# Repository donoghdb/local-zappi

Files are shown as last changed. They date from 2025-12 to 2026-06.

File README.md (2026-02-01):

# Myenergi Zappi V2.x Local Controller (ESP32-S3)

<p align="center">
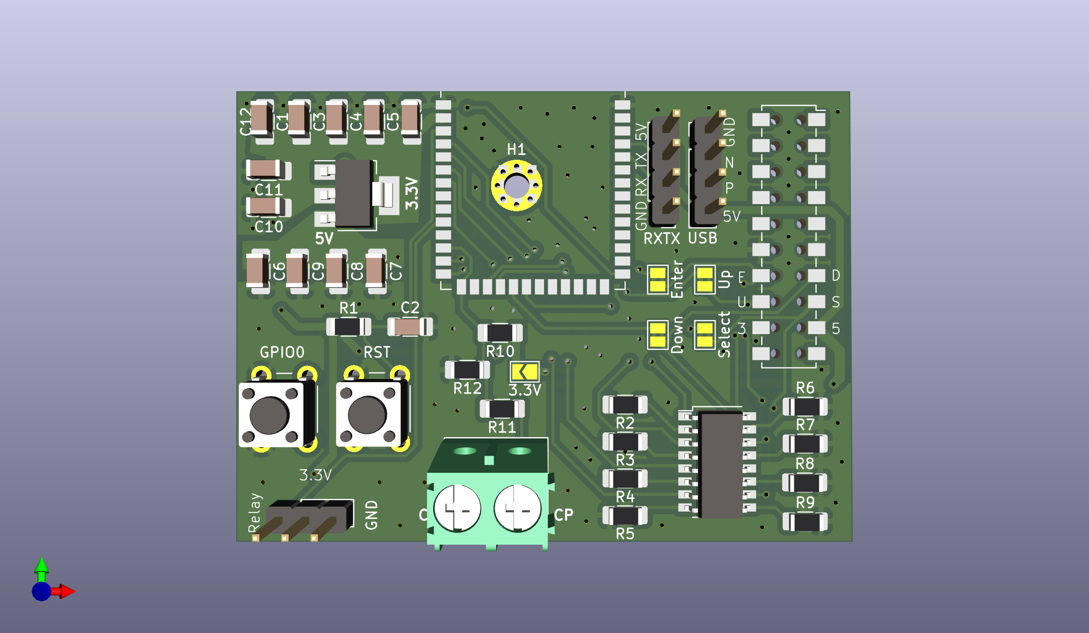
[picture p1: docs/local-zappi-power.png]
  
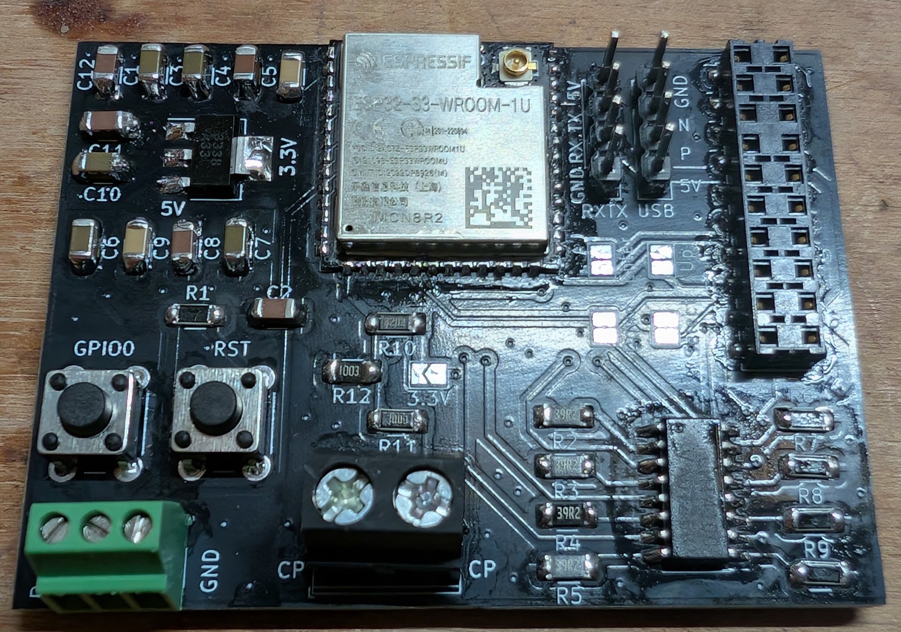
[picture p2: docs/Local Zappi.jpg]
  
</p>

A dedicated hardware implant for Myenergi Zappi V2.x EV Chargers. This project interfaces directly with the Zappi's internal control bus to provide **Local MQTT**, **Home Assistant**, and **Web Control** without relying on the Myenergi Cloud or Hub. It is intended to action on the 4 external buttons while monitoring the EVSE CP line conversation between the Zappi and the car. It does not affect the software of the Zappi nor does it affect anything else. So it can be removed without affecting anything else.

## ⚠️ DANGER: HIGH VOLTAGE
**This device is installed INSIDE a 240V/400V EV Charger.**
* **Isolate power completely** at the consumer unit/breaker before opening the Zappi.
* High voltage components are centimeters away from the installation area.
* **Use at your own risk.** Improper installation can damage your charger, vehicle, or cause injury.

## 🔌 How It Works
This PCB intercepts the connection between the Zappi **Main Control Board** and the **Front Panel (Display & Buttons)**.

1.  **Power (5V):** Draws power directly from the Zappi's internal 5V rail (no external USB power needed).
2.  **Button Interface:**
    * **Read Mode:** Monitors the 4 physical buttons (Enter, Up, Down, Select) so you can still use the Zappi manually.
    * **Write Mode:** Simulates button presses using Optocouplers/Relays, allowing you to control the menu remotely via WiFi.
3.  **J1772 Pilot Reading:**
    * Taps into the CP (Control Pilot) line to detect accurate Status (A-F) and PWM Duty Cycle (Amps).

## 🛠️ Hardware Interface
The design utilizes an **ESP32-S3-WROOM-1** and integrates via the internal 20-pin Ribbon Header.

| Signal | Function | Connection |
| :--- | :--- | :--- |
| **5V / GND** | Power Supply | Taken from Zappi internal header. |
| **Buttons** | Enter, Up, Down, Select | **Bi-directional:** Reads physical presses & triggers simulated presses via Optocouplers (TCMT4100). |
| **CP Signal** | J1772 State Detection | Read ±12V Pilot Signal. |
| **Boost Relay** | e-Sense Port trigger | Enable via relay. |

### Pinout Configuration (ESP32-S3)
*Based on PCB Revision 1.1*
* **Button Inputs:** GPIO 4, 5, 6, 7
* **Button Triggers:** GPIO 12, 13, 14, 15
* **CP Signal (ADC):** GPIO 8
* **CP Interrupt:** GPIO 3
* **Relay:** GPIO 17

## 💻 Software / Firmware
This project supports two firmware paths depending on your needs:

### Option A: ESPHome (Not complete yet)
Best for **Home Assistant** users. Provides native integration with zero coding.
* Exposes Buttons as simple HA Switches.
* Exposes Charging Amps and State as Sensors.
* **Config:** Copy `esphome/zappi.yaml` and `esphome/zappi_logic.h` to your ESPHome directory.
* Limitations: Does not monitor or track the menu position. The monitoring of the Zappi buttons is not tested yet.

### Option B: Custom C++ Firmware (Best Option)
Best for standalone use or custom MQTT setups.
## 🌟 Features
* **Full Local Control:** No cloud dependency. Works with Home Assistant via MQTT.
* **Offline Scheduler:** Set Start/End times directly on the device via text input (e.g., "07:30"). It handles the mode switching (Stopped ↔ Fast) automatically.
* **Robust Time Sync:**
    * **Primary:** NTP via Google/NIST (Direct IP to bypass DNS issues).
    * **Backup:** "Push" time via MQTT from Home Assistant (works during internet outages).
    * **Safety:** Scheduler only activates once the system year is verified > 2020.
* **Live Monitoring:** View Charging State, Pilot Amps, Duty Cycle, and RSSI.
* **Menu Navigation:** Remotely navigate the Zappi menu using the Web UI or HA.
* **Reliability:** Includes "Last Will & Testament" (LWT) so Home Assistant immediately knows if the device loses power.
* **Others:** Web Interface, WebSocket Live Data, WebSerial, OTA Updates.
* **Tech Stack:** PlatformIO, AsyncWebServer.

## 🔐 Configuration (Custom Firmware)

To keep your WiFi and MQTT passwords safe, this project uses a separate credentials file that is **ignored by Git**.

### 1. Create `src/credentials.cpp`
Create a new file in the `src/` folder named `credentials.cpp` and copy the code below. **Update the values with your actual network details.**

```cpp
#include "credentials.h"
#include <Arduino.h> // for IPAddress

// WiFi Credentials
const char* ssid = "YOUR_WIFI_SSID";
const char* password = "YOUR_WIFI_PASSWORD";

// MQTT Broker Details
const char* mqttServer = "192.168.1.50";
const int mqttPort = 1883;
const char* mqttUser = "homeassistant";
const char* mqttPassword = "mqtt_password";
const char* mqttClientId = "Zappi_Controller";

// Static IP Configuration (Optional)
// Set to 0.0.0.0 if you want to use DHCP
IPAddress staticIP(192, 168, 1, 200);
IPAddress gateway(192, 168, 1, 1);
IPAddress subnet(255, 255, 255, 0);
```

### 2. MQTT Topics
The device uses the base topic `zappi/` (configurable).
* **Controls:** `zappi/button/...`
* **Sensors:** `zappi/sensor/...`
* **Status:** `zappi/status` (online/offline)
* **Scheduler:**
    * Enable: `zappi/switch/zap_sch_en/command` (ON/OFF)
    * Start Time: `zappi/text/zap_sch_start/set` (HH:MM)
    * End Time: `zappi/text/zap_sch_end/set` (HH:MM)
    * Force Time Sync: `zappi/time/set_epoch` (Epoch Timestamp)

## ⚡ Installation (Custom Firmware / PlatformIO)

This method allows you to use the full Web Interface and custom C++ logic.

### 1. Initial Setup (USB)
1.  Clone this repository and open the `firmware_custom` folder in **VS Code** with the **PlatformIO** extension installed.
2.  Connect your ESP32-S3 to your computer via USB.
3.  Open `platformio.ini` and ensure the OTA lines are **commented out** (so it uses USB upload by default):
    ```ini
    ; upload_protocol = espota
    ; upload_port = 192.168.1.X
    ```
4.  Click the **Upload** arrow (→) in the bottom toolbar to flash the firmware.

### 2. Upload the Web Interface (Filesystem)
The HTML files live in a separate partition called LittleFS. You must upload this once, or the web page will be blank.

1.  Click the **PlatformIO Alien Icon** on the left sidebar.
2.  Navigate to: **Project Tasks** → **Platform**.
3.  Click **Upload Filesystem Image**.
4.  Wait for the success message. Your ESP32 will reboot.
5.  The HTML can be updated directly from the webserver later via an Upload page.

### 3. Connect & Use
1.  Search for the WiFi Network: `Zappi-AP` (Password: `password123` or as configured).
2.  Navigate to `http://192.168.4.1` (or the IP assigned by your router).
3.  You should see the Zappi Control Dashboard.

### 4. Future Updates via OTA (Wireless)
Once the device is installed inside the Zappi case, you can update it wirelessly:
1.  Find the IP address of your Zappi Controller (e.g., `192.168.1.50`).
2.  Edit `platformio.ini` and uncomment the OTA lines:
    ```ini
    upload_protocol = espota
    upload_port = 192.168.1.50  ; Replace with your actual IP
    ```
3.  Click **Upload** in PlatformIO. It will now flash over WiFi.

## 🔧 Hardware Installation Guide
1.  **Power Off:** Turn off the Zappi at the breaker.
2.  **Open Case:** Remove the front fascia and unscrew the main cover.
3.  **Locate Header:** Find the 20-pin pin header connecting the main PCB to the screen module.
4.  **Seperate boards:** Use a needle nose pliers to compress each corner connecting pin and carfully seperate the boards.
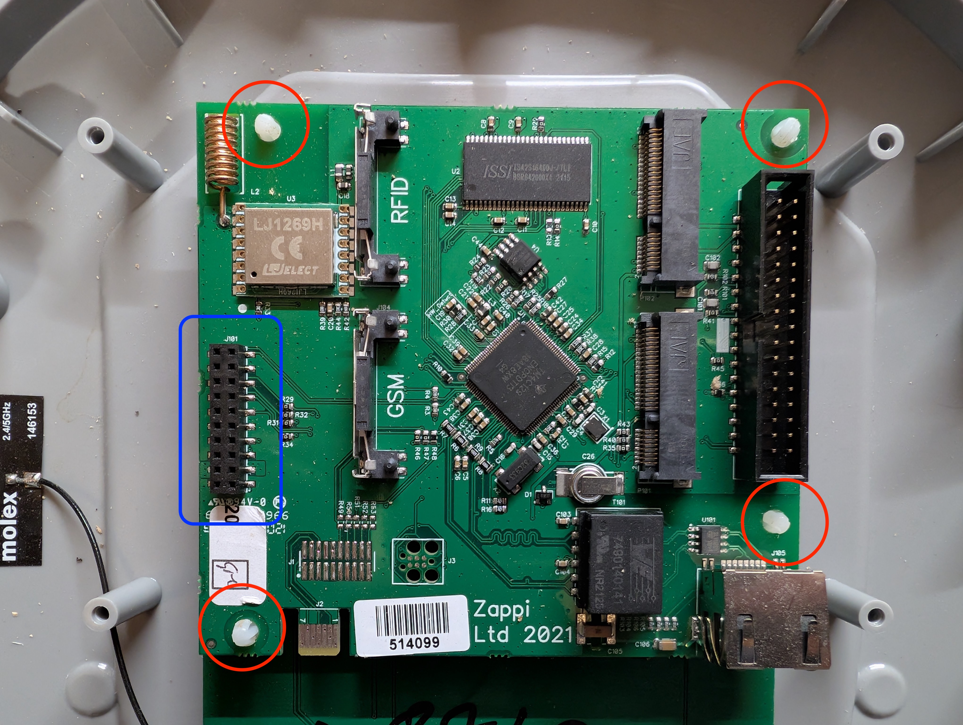
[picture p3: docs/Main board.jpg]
20 pin in Blue, connecting pins in Red

5.  **Extend Header:** Extend the header using this component Samtec EW-10-12-G-D-250 or this one EW-10-13-G-D-200.
6.  **Connect:** With the extended header connect the boards back together and then attach the ESP32 board.
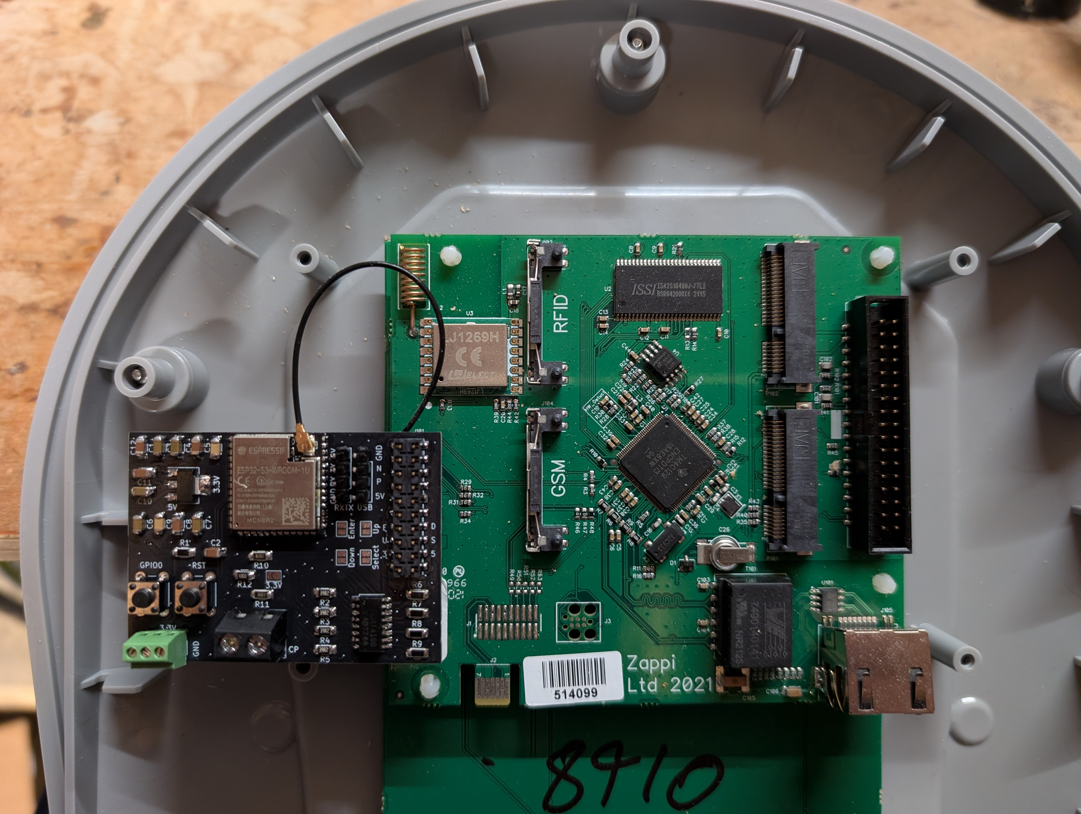
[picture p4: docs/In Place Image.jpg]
Local ESP32 in place, with Molex connector for Wifi

7.  **Connect CP:** Attach the single sensing wire to the CP terminal block.
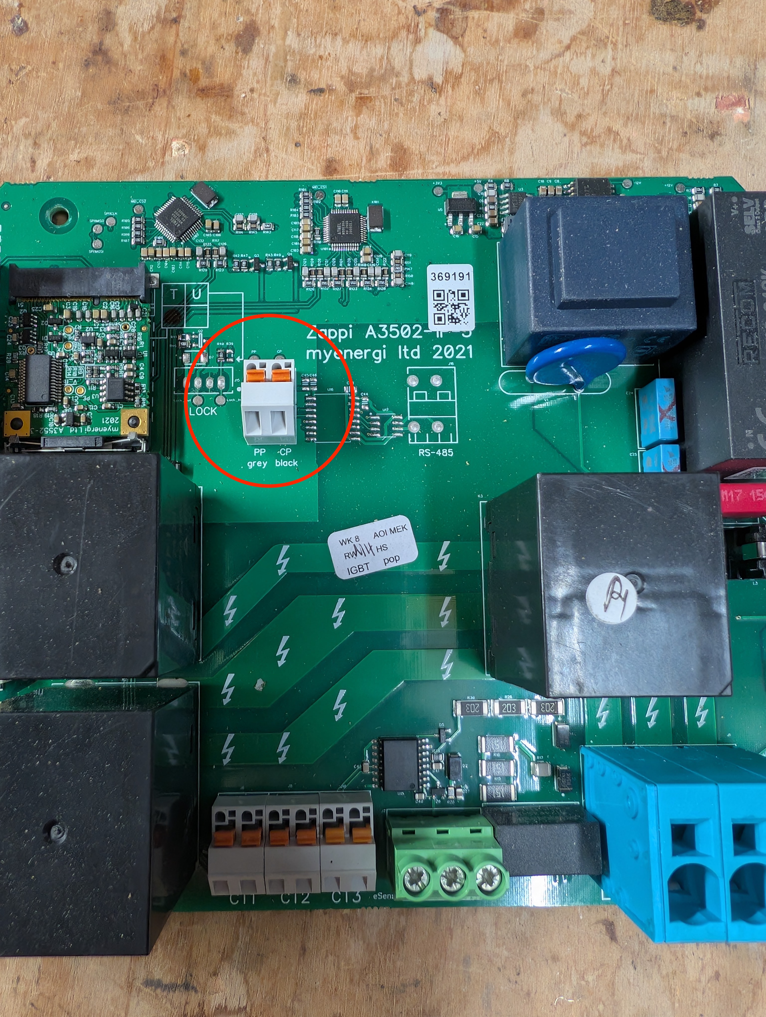
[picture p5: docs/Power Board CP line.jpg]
Attach or Extend the CP line to the ESP32

8.  **e-Sence:** Attached the 24V output of the zappi power board to the Common Relay connector and the Normally Closed to the e-Sence input on the zappi power board.
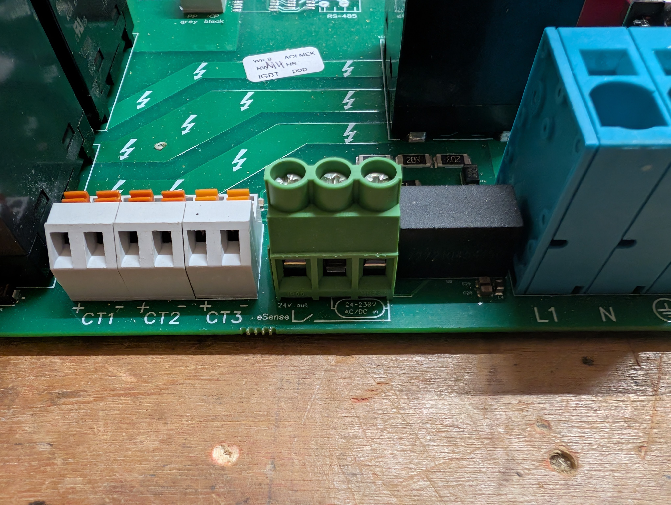
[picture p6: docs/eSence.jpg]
eSence connection 24V to Input via Relay

9.  **Wifi:** Attach the Zappi existing antenna to the new board or install a new on. Or else create it with this varient ESP32-S3-WROOM-1-N8R2
10.  **Close & Power Up:** Reassemble and restore power.

## 🔌 Schematic
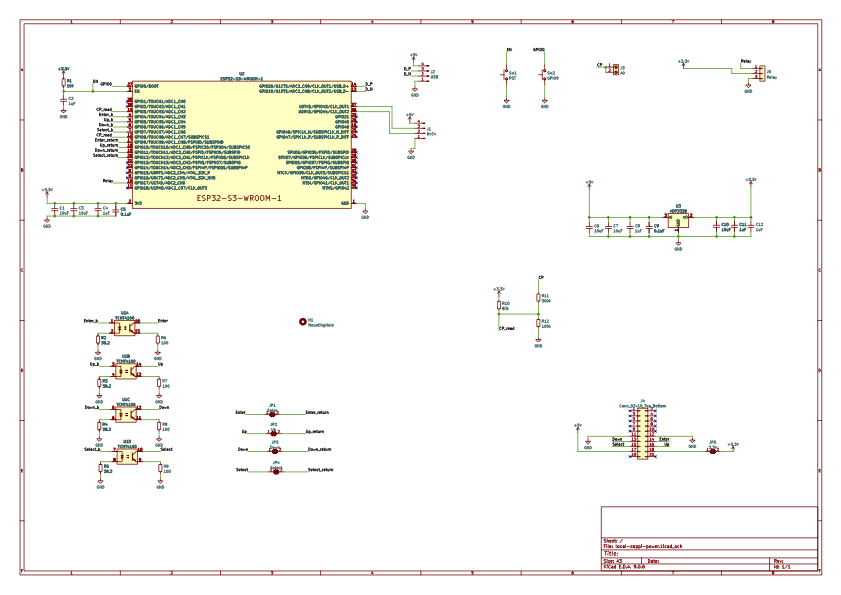
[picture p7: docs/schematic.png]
Schematic Preview

*[Download Full PDF Schematic](docs/local-zappi-power.pdf)*

## 🧩 Bill of Materials (BOM)

This project requires a custom PCB or a perfboard setup designed to fit inside the Zappi case.
There is more Decoupling capacitators than required. Sometimes the power rails dip when the Zappi triggers its own relays. 

### Active Components
| Ref | Component | Description | Notes |
| :--- | :--- | :--- | :--- |
| **U2** | **ESP32-S3-WROOM-1** | MCU Module | Schematic specifies WROOM-1 (PCB Antenna). If using the `1U` version, connect an external IPEX antenna. |
| **U3** | **ADP3338** | 3.3V LDO Regulator | Steps down the Zappi 5V rail to 3.3V for the ESP32. |
| **U1** | **TCMT4100** | Quad Optocoupler | **U1:** Simulates button presses. |

### Passive Components
| Ref | Value | Quantity | Description |
| :--- | :--- | :--- | :--- |
| **R1** | **10kΩ** | 1 | Pull up to 3.3V for ESP32 Enable Pin. |
| **R2-R5** | **39.2Ω** | 4 | Current limiting for Optocoupler LEDs. |
| **R6-R9** | **100Ω** | 4 | Pull/Protection for button return lines. |
| **R10** | **82kΩ** | 1 | Pull up to 3.3V Pilot Signal divider (CP to ADC), 1% Tolerance required. |
| **R11** | **300kΩ** | 1 | High-side Pilot Signal divider (CP to ADC), 1% Tolerance required. |
| **R12** | **100kΩ** | 1 | Low-side Pilot Signal divider (ADC to GND), 1% Tolerance required. |
| **C6, C7, C10, C1, C3** | **10µF** | 4 | Bulk capacitance for LDO & 3.3V Rails. |
| **C2, C4, C8, C11, C12** | **1µF** | 4 | Stability capacitance for LDO. |
| **C5, C9** | **0.1µF** | 2 | Decoupling for ESP32 and Power rails. |

### Connectors
| Component | Quantity | Purpose |
| :--- | :--- | :--- |
| **20-Pin Header** | 1 | 2x10 Samtec (HLE-110-02-L-DV-BE-K-TR) to interface with Zappi mainboard. |
| **2-Pin Terminal** | 1 | Screw terminal for CP (Pilot) wire connection. |
| **3-Pin Header/Terminal** | 1 | Optional Relay/GPIO breakout (JP5). |
| **Buttons** | 2 | Reset and GPIO 0 button. |
| **Mini Relay** | 1 | Optional: Adafruit STEMMA Non-Latching Mini Relay. |

## 🕒 Scheduler & Time Sync
The device includes a **System Time Sensor** (`sensor.system_time`) to show you exactly what time the internal clock thinks it is.

### How it works:
1.  **On Boot:** The device attempts to sync time via NTP using Google & NIST IPs (bypassing local DNS issues).
2.  **Safety Check:** The scheduler **will not run** until the year is > 2020. This prevents the charger from triggering at the wrong time (e.g., 1970).
3.  **Offline Backup:** If your internet is down, Home Assistant can "push" the time to the Zappi via MQTT automation using the topic `zappi/time/set_epoch`.

## 🧪 Testing the CP (Pilot) Signal (Optional Extra if you want to verify the device before installing it)

The Control Pilot (CP) line communicates the state of the EVSE to the car using specific voltage levels (+12V, +9V, +6V) and a 1kHz PWM signal.

Since we are using a **Passive Resistor Divider (300kΩ / 100kΩ)**, it is critical to verify the voltage levels before relying on the automation.

### 1. Bench Testing 
Before installing the unit into the Zappi, you can verify the voltage divider logic using a DC Power Supply or a simple 9V battery.

1.  **Disconnect the ESP32** (if possible) or ensure it is unpowered.
2.  **Apply Voltage** to the CP Terminal on your custom board:
    * **Input 12V:** Measure the voltage at the ESP32 GPIO 8 pin. It should be **~3.0V**.
    * **Input 9V:** Measure the voltage at GPIO 8. It should be **~2.25V**.
3.  **Verify:** If you see >3.3V at the GPIO pin, **STOP**. Your resistor values are incorrect, and you risk frying the ESP32.

### 2. Live Signal Verification
Once installed in the Zappi, use the **WebSerial** (Custom Firmware) or **Home Assistant Logs** (ESPHome) to view the raw ADC readings.

#### Expected ADC Values (12-bit Resolution)
The code looks for the **Peak Voltage** of the signal. Here is what you should see in the logs:

| State | J1772 Voltage | Divider Output | Target ADC Raw |
| :--- | :--- | :--- | :--- |
| **A (Unplugged)** | +12V | ~3.0V | **3600 - 4095** |
| **B (Connected)** | +9V | ~2.25V | **3100 - 3600** |
| **C (Charging)** | +6V (PWM) | ~1.5V | **2500 - 3100** |
| **D (Ventilation)** | +3V (PWM) | ~0.75V | **1900 - 2500** |
| **F (Error/Fault)** | -12V | -3.0V* | **< 1500** |

*> **Note:** The passive divider will pass negative voltages to the GPIO. Ensure your protection diode is in place, or that the ESP32 inputs are clamped effectively to prevent damage during State F.*

### 3. Verifying Amperage (PWM)
When the car enters **State C (Charging)**, the Zappi generates a 1kHz Square Wave.
1.  Check the **"Zappi Duty Cycle"** sensor.
2.  Compare it to the Zappi Screen.
    * **Formula:** `Amps = Duty Cycle x 0.6`
    * *Example:* A 50% Duty Cycle should display as **30A**.

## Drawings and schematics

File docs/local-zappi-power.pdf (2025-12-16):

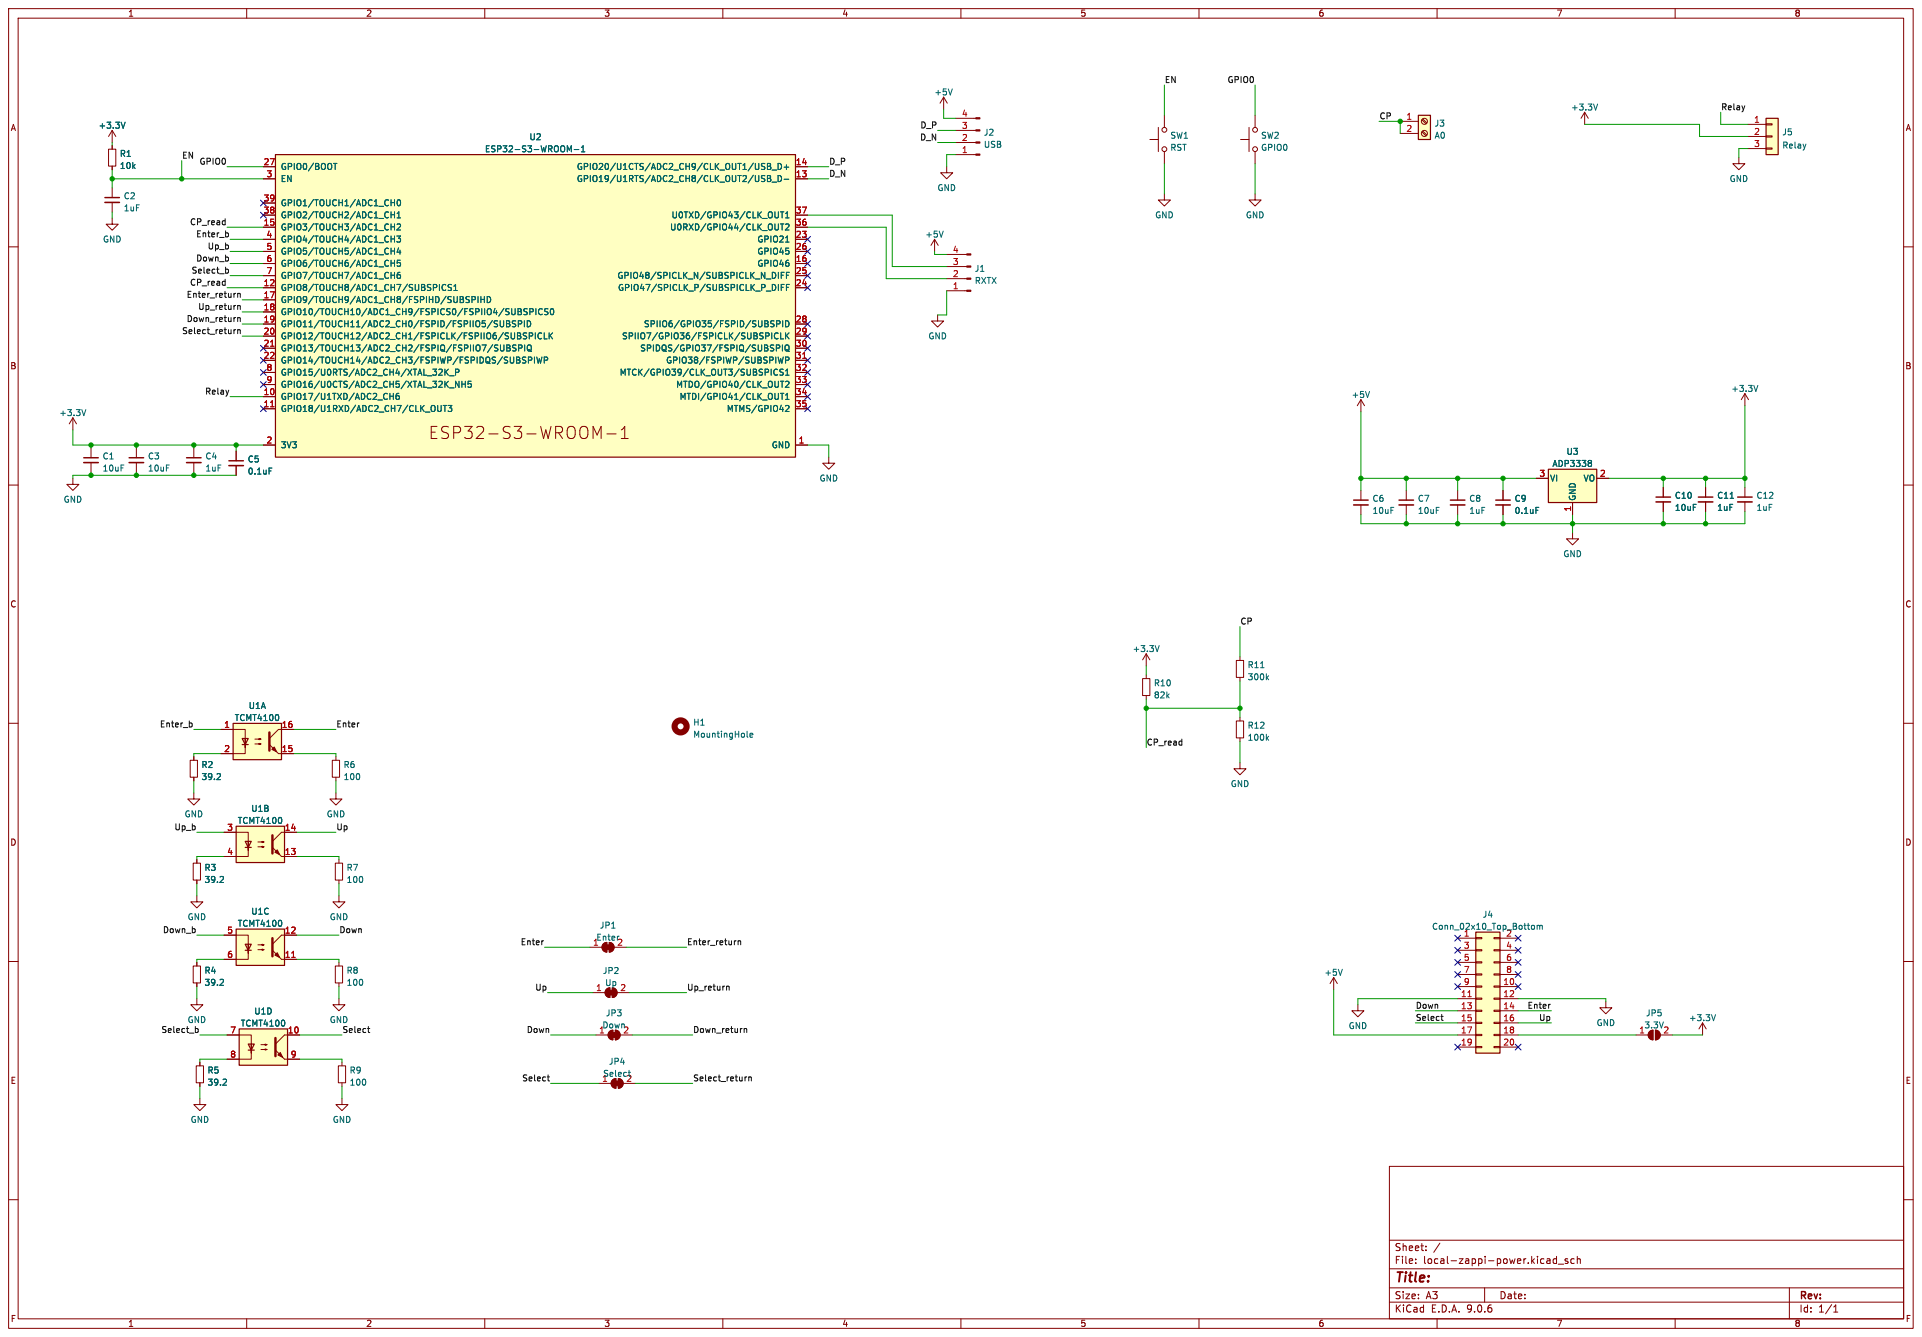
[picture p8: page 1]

1 VO 2 U2 ESP32-S3-WROOM-1 GPIO0/BOOT 27 EN 3 GPIO1/TOUCH1/ADC1_CH0 39 GPIO2/TOUCH2/ADC1_CH1 38 GPIO3/TOUCH3/ADC1_CH2 15 GPIO4/TOUCH4/ADC1_CH3 4 GPIO5/TOUCH5/ADC1_CH4 5 GPIO6/TOUCH6/ADC1_CH5 6 GPIO7/TOUCH7/ADC1_CH6 7 GPIO8/TOUCH8/ADC1_CH7/SUBSPICS1 12 GPIO9/TOUCH9/ADC1_CH8/FSPIHD/SUBSPIHD 17 GPIO10/TOUCH10/ADC1_CH9/FSPICS0/FSPIIO4/SUBSPICS0 18 GPIO11/TOUCH11/ADC2_CH0/FSPID/FSPIIO5/SUBSPID 19 GPIO12/TOUCH12/ADC2_CH1/FSPICLK/FSPIIO6/SUBSPICLK 20 GPIO13/TOUCH13/ADC2_CH2/FSPIQ/FSPIIO7/SUBSPIQ 21 GPIO14/TOUCH14/ADC2_CH3/FSPIWP/FSPIDQS/SUBSPIWP 22 GPIO15/U0RTS/ADC2_CH4/XTAL_32K_P 8 GPIO16/U0CTS/ADC2_CH5/XTAL_32K_NH5 9 GPIO17/U1TXD/ADC2_CH6 10 GPIO18/U1RXD/ADC2_CH7/CLK_OUT3 11

Id: 1/1 Title: File: local-zappi-power.kicad_sch Sheet: /

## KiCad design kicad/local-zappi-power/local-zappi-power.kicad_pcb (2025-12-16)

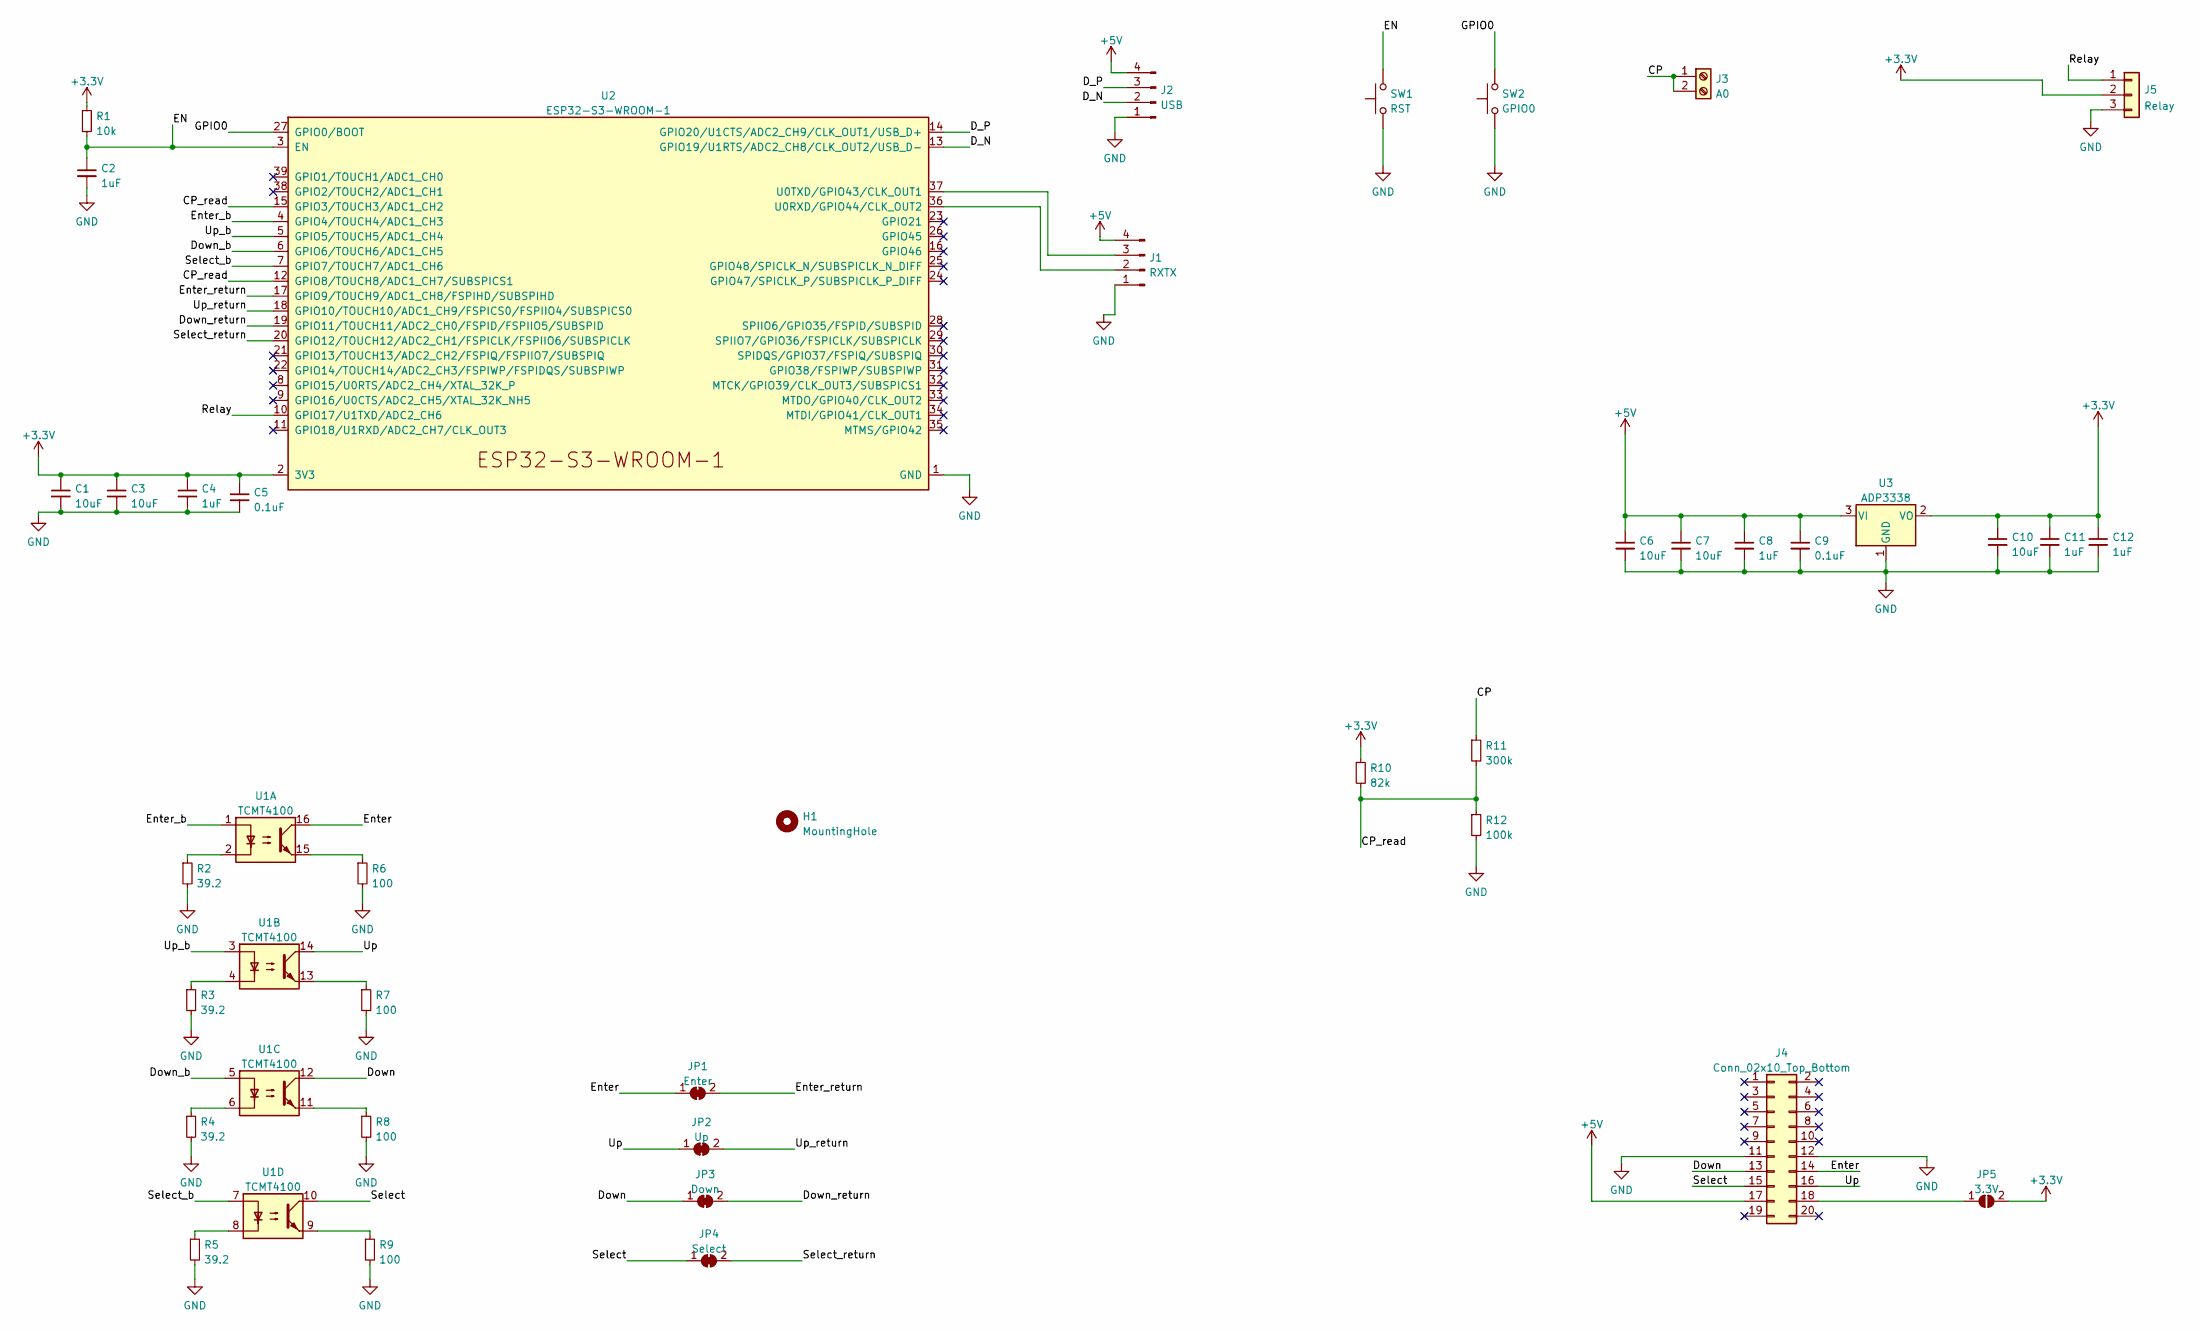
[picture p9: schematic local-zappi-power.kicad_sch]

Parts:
C1, C3, C6, C7, C10: 10uF; C_1206_3216Metric_Pad1.33x1.80mm_HandSolder; Mouser GMK316BJ106KL-T
C2, C4, C8, C11, C12: 1uF; C_1206_3216Metric_Pad1.33x1.80mm_HandSolder; Mouser 12065C105K4Z4A
C5, C9: 0.1uF; C_1206_3216Metric_Pad1.33x1.80mm_HandSolder; Mouser 581-KAM31NR72A104KU
H1: MountingHole; MountingHole_2.5mm_Pad_Via
J1: RXTX; PinHeader_1x04_P2.54mm_Vertical
J2: USB; PinHeader_1x04_P2.54mm_Vertical
J3: A0; TerminalBlock_Phoenix_PT-1,5-2-5.0-H_1x02_P5.00mm_Horizontal; Mouser 651-5441537
J4: Conn_02x10_Top_Bottom; Samtec_HLE-110-02-xxx-DV-BE_2x10_P2.54mm_Horizontal
J5: Relay; PinHeader_1x03_P2.54mm_Vertical
JP1: Enter; SolderJumper-2_P1.3mm_Bridged2Bar_Pad1.0x1.5mm
JP2: Up; SolderJumper-2_P1.3mm_Bridged2Bar_Pad1.0x1.5mm
JP3: Down; SolderJumper-2_P1.3mm_Bridged2Bar_Pad1.0x1.5mm
JP4: Select; SolderJumper-2_P1.3mm_Bridged2Bar_Pad1.0x1.5mm
JP5: 3.3V; SolderJumper-2_P1.3mm_Open_TrianglePad1.0x1.5mm
R1: 10k; R_1206_3216Metric_Pad1.30x1.75mm_HandSolder; Mouser CRCW120610K0FKEA
R2, R3, R4, R5: 39.2; R_1206_3216Metric_Pad1.30x1.75mm_HandSolder; Mouser CRCW120639R2FKEAC
R6, R7, R8, R9: 100; R_1206_3216Metric_Pad1.30x1.75mm_HandSolder; Mouser CRCW1206100RJNEA
R10: 82k; R_1206_3216Metric_Pad1.30x1.75mm_HandSolder; Mouser ESR18EZPF8202
R11: 300k; R_1206_3216Metric_Pad1.30x1.75mm_HandSolder; Mouser KTR18EZPF3003
R12: 100k; R_1206_3216Metric_Pad1.30x1.75mm_HandSolder; Mouser CRGP1206F100K
SW1: RST; SW_PUSH_6mm_H4.3mm
SW2: GPIO0; SW_PUSH_6mm_H4.3mm
U1: TCMT4100; SOP-16_4.4x10.4mm_P1.27mm
U2: ESP32-S3-WROOM-1
U3: ADP3338; SOT-223-3_TabPin2; Mouser 584-ADP3338AKCZ3.3R

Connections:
+3.3V: C1.1, C3.1, C4.1, C5.1, C10.1, C11.1, C12.1, J5.2, JP5.2 (B), R1.1, R10.1, U2.2 (3V3), U3.2 (VO)
+5V: C6.1, C7.1, C8.1, C9.1, J1.4, J2.4, J4.17, U3.3 (VI)
/CP: J3.1, J3.2, R11.1
/CP_read: R10.2, R11.2, R12.1, U2.12 (GPIO8/TOUCH8/ADC1_CH7/SUBSPICS1), U2.15 (GPIO3/TOUCH3/ADC1_CH2)
/D_N: J2.2, U2.13 (GPIO19/U1RTS/ADC2_CH8/CLK_OUT2/USB_D-)
/D_P: J2.3, U2.14 (GPIO20/U1CTS/ADC2_CH9/CLK_OUT1/USB_D+)
/Down: J4.13, JP3.1 (A), U1.12
/Down_b: U1.5, U2.6 (GPIO6/TOUCH6/ADC1_CH5)
/Down_return: JP3.2 (B), U2.19 (GPIO11/TOUCH11/ADC2_CH0/FSPID/FSPIIO5/S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)
/EN: C2.1, R1.2, SW1.2, U2.3 (EN)
/Enter: J4.14, JP1.1 (A), U1.16
/Enter_b: U1.1, U2.4 (GPIO4/TOUCH4/ADC1_CH3)
/Enter_return: JP1.2 (B), U2.17 (GPIO9/TOUCH9/ADC1_CH8/FSPIHD/SUBSPIHD)
/GPIO0: SW2.2, U2.27 (GPIO0/BOOT)
/Relay: J5.1, U2.10 (GPIO17/U1TXD/ADC2_CH6)
/Select: J4.15, JP4.1 (A), U1.10
/Select_b: U1.7, U2.7 (GPIO7/TOUCH7/ADC1_CH6)
/Select_return: JP4.2 (B), U2.20 (GPIO12/TOUCH12/ADC2_CH1/FSPICLK/FSPIIO6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)
/Up: J4.16, JP2.1 (A), U1.14
/Up_b: U1.3, U2.5 (GPIO5/TOUCH5/ADC1_CH4)
/Up_return: JP2.2 (B), U2.18 (GPIO10/TOUCH10/ADC1_CH9/FSPICS0/FSPIIO4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)
GND: C1.2, C2.2, C3.2, C4.2, C5.2, C6.2, C7.2, C8.2, C9.2, C10.2, C11.2, C12.2, H1.1, J1.1, J2.1, J4.11, J4.12, J5.3, R2.2, R3.2, R4.2, R5.2, R6.2, R7.2, R8.2, R9.2, R12.2, SW1.1, SW2.1, U2.1 (GND), U2.40 (GND), U2.41 (GND), U3.1 (GND)
unnamed: J1.2, U2.36 (U0RXD/GPIO44/CLK_OUT2)
unnamed: J1.3, U2.37 (U0TXD/GPIO43/CLK_OUT1)
unnamed: J4.18, JP5.1 (A)
unnamed: R2.1, U1.2
unnamed: R3.1, U1.4
unnamed: R4.1, U1.6
unnamed: R5.1, U1.8
unnamed: R6.1, U1.15
unnamed: R7.1, U1.13
unnamed: R8.1, U1.11
unnamed: R9.1, U1.9

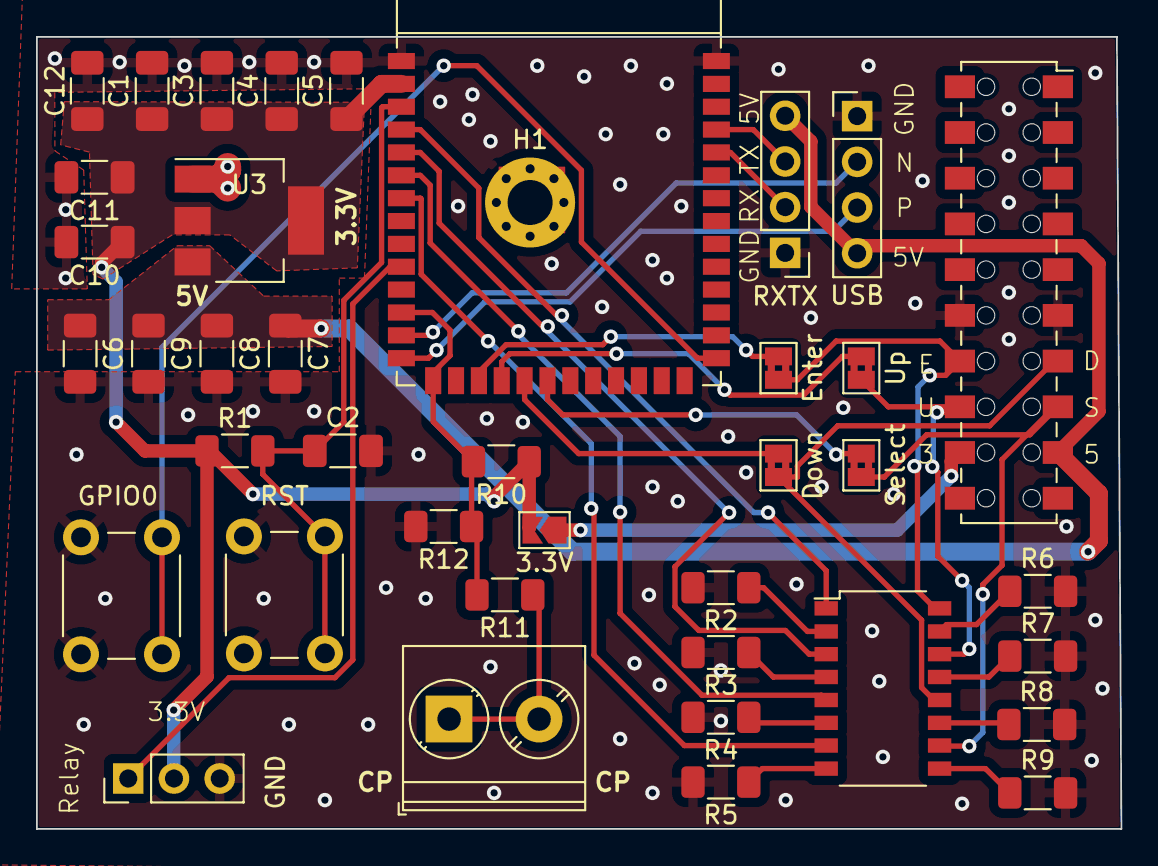
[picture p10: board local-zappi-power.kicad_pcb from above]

Board: 2 copper layers, 60.2 x 44.0 mm, 40 parts (0 on the bottom side), 33 nets.

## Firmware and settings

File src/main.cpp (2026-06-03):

#include <Arduino.h>
#include "globals.h"
#include "hardware.h"
#include "menu_system.h"
#include "wifi_mqtt.h"
#include "web_server.h"
#include <ArduinoOTA.h>
#include "credentials.h"
#include <ESPmDNS.h>
#include <esp_task_wdt.h>
#include <esp_ota_ops.h>
#include <esp_partition.h>
#include "soc/soc.h"
#include "soc/rtc_cntl_reg.h"



void setup() {
  WRITE_PERI_REG(RTC_CNTL_BROWN_OUT_REG, 0); // Disable Brownout Detector
  Serial.begin(115200);
  DEBUG_PRINTLN("Zappi Controller Starting...");

  // 1. Data & Globals
  prefs.begin("zappi", false);
  currentMode = prefs.getInt("currentMode", 1);
  counterDirty = false;
  // Load Schedule from Memory (NVS)
  schedEnabled   = prefs.getBool("schedEnabled", true);
  schedStartHour = prefs.getInt("schedStartH", 2); // 2 AM
  schedStartMin  = prefs.getInt("schedStartM", 0);
  schedEndHour   = prefs.getInt("schedEndH", 6); // 6 AM
  schedEndMin    = prefs.getInt("schedEndM", 0);
  

  // 2. Hardware (Pins & Interrupts)
  setupHardware();
  setupLogMenus();
  setupChargeSettingsMenus();

  // 3. START TASKS
  // ============================================================
  xTaskCreatePinnedToCore(counterNvsTask, "CounterNVS", 4096, NULL, 1, &counterNvsTaskHandle, 1);
  xTaskCreatePinnedToCore(buttonReleaseTask, "BtnRelTask", 4096, NULL, 1, &buttonReleaseTaskHandle, 1);
  xTaskCreatePinnedToCore(returnHandlerTask, "ReturnTask", 4096, NULL, 2, &returnHandlerTaskHandle, 1);
  xTaskCreatePinnedToCore(rssiPublishTask, "RSSITask", 4096, NULL, 1, &rssiPublishTaskHandle, 1);
  xTaskCreatePinnedToCore(adcMeasurementTask, "ADCTask", 10000, NULL, 1, &updateADC, 0); // Core 0 for ADC
  // ============================================================

  // 4. Create Timers
  mqttReconnectTimer = xTimerCreate("mqttTimer", pdMS_TO_TICKS(5000), pdFALSE, nullptr, [](TimerHandle_t) { connectToMqtt(); });
  wifiReconnectTimer = xTimerCreate("wifiTimer", pdMS_TO_TICKS(5000), pdFALSE, nullptr, [](TimerHandle_t) { connectToWifi(); });
  
  // Menu Timer (Prevent crash on menu open)
  menuTimeoutTimer = xTimerCreate("menuTimer", pdMS_TO_TICKS(3600000), pdFALSE, (void*)0, [](TimerHandle_t xTimer){
      extern void resetMenuToOff();
      resetMenuToOff(); 
  });

  // 5. Network Configuration
  WiFi.onEvent([](WiFiEvent_t event, WiFiEventInfo_t info){
      // Call your original callback
      wifiConnected(event, info);
      
      // AND restart mDNS now that we are 100% sure we have an IP
      if (MDNS.begin("evcharger")) {
         MDNS.addService("http", "tcp", 80);
         DEBUG_PRINTLN("mDNS restarted: http://evcharger.local");
      }
  }, ARDUINO_EVENT_WIFI_STA_GOT_IP);
  WiFi.onEvent(wifiDisconnected, ARDUINO_EVENT_WIFI_STA_DISCONNECTED);
  
  // Start WiFi BEFORE WebServer to prevent "Invalid mbox" crash
  // WiFi.config(staticIP, gateway, subnet); 
  connectToWifi(); 
  
  // 6. Setup Services 
  setupMqtt();
  setupWebServer(); 
  
  // 7. OTA with Watchdog Handling
  ArduinoOTA.onStart([]() {
    mqttLog("System: Wireless OTA Update Started...");
    String type = (ArduinoOTA.getCommand() == U_FLASH) ? "sketch" : "filesystem";
    DEBUG_PRINTLN("OTA Update Start: " + type);

    // 1. DISABLE WATCHDOG (Crucial!)
    // We tell the watchdog: "Ignore the main loop for a while, I'm busy updating."
    esp_task_wdt_delete(NULL);

    // 2. Disable Sleep & Detach Interrupts (Prevent hardware interference)
    WiFi.setSleep(false);
    detachInterrupt(digitalPinToInterrupt(adcInterruptPin)); 
    for(int i=0; i<4; i++) {
        detachInterrupt(digitalPinToInterrupt(returnButtonPins[i]));
    }

    // 3. Suspend Tasks
    if (updateADC != NULL) vTaskSuspend(updateADC);
    if (rssiPublishTaskHandle != NULL) vTaskSuspend(rssiPublishTaskHandle);
    if (buttonReleaseTaskHandle != NULL) vTaskSuspend(buttonReleaseTaskHandle);
    if (counterNvsTaskHandle != NULL) vTaskSuspend(counterNvsTaskHandle);
    
    // 4. Stop Menu Timer
    if (menuTimeoutTimer != NULL) xTimerStop(menuTimeoutTimer, 0);
  });

  ArduinoOTA.onEnd([]() {
    mqttLog("System: OTA Update Successful! Rebooting...");
    DEBUG_PRINTLN("\nOTA Update End");
    // Device usually reboots here, but if not, re-enable safety:
    esp_task_wdt_add(NULL); 
  });

  ArduinoOTA.onProgress([](unsigned int progress, unsigned int total) {
    // Only print every 10% to save CPU cycles
    static int lastPercent = 0;
    int percent = (progress / (total / 100));
    if (percent - lastPercent >= 10) {
        DEBUG_PRINTF("OTA: %u%%\r", percent);
        lastPercent = percent;
    }
  });

  ArduinoOTA.onError([](ota_error_t error) {
    mqttLog("System ERROR: OTA Update Failed!");
    DEBUG_PRINTF("Error[%u]: ", error);
    
    // If update failed, we MUST restart the Watchdog and Hardware
    esp_task_wdt_add(NULL); 
    
    // Restore Interrupts
    attachInterrupt(digitalPinToInterrupt(adcInterruptPin), handleInterrupt, CHANGE);
    attachInterrupt(digitalPinToInterrupt(returnButtonPins[0]), handleReturn0, CHANGE);
    attachInterrupt(digitalPinToInterrupt(returnButtonPins[1]), handleReturn1, CHANGE);
    attachInterrupt(digitalPinToInterrupt(returnButtonPins[2]), handleReturn2, CHANGE);
    attachInterrupt(digitalPinToInterrupt(returnButtonPins[3]), handleReturn3, CHANGE);

    // Resume Tasks
    if (updateADC != NULL) vTaskResume(updateADC);
    if (rssiPublishTaskHandle != NULL) vTaskResume(rssiPublishTaskHandle);
    if (buttonReleaseTaskHandle != NULL) vTaskResume(buttonReleaseTaskHandle);
    if (counterNvsTaskHandle != NULL) vTaskResume(counterNvsTaskHandle);
  });

  ArduinoOTA.begin();
  
  // 8. Initial State
  updateChargerState(currentMode);

  // Initialize Watchdog with a 5-second timeout
  // If the loop() doesn't run for 5 seconds, the ESP32 reboots.
  esp_task_wdt_init(5, true); 
  esp_task_wdt_add(NULL); // Add the current thread (Loop) to the watchdog


  // 9. CHECK FOR OTA UPDATE
  const esp_partition_t *running = esp_ota_get_running_partition();
  esp_ota_img_states_t ota_state;
  if (esp_ota_get_state_partition(running, &ota_state) == ESP_OK) {
      if (ota_state == ESP_OTA_IMG_PENDING_VERIFY) {
          DEBUG_PRINTLN("OTA Update Detected! Verifying stability...");
          // We do NOT mark valid yet. We wait for MQTT connection.
          // If we crash or watchdog reset before MQTT connects, 
          // the bootloader will rollback to the old version automatically.
      }
  }
}

unsigned long lastScheduleCheck = 0;

void checkSchedule() {
  // 1. Throttle: Only run this check once every 5 seconds
  if (millis() - lastScheduleCheck < 5000) return;
  lastScheduleCheck = millis();

  if (!schedEnabled) return;

  // 2. THE FIX: Check 'Epoch Time' first (Non-Blocking)
  time_t now;
  time(&now);
  
  if (now < 1600000000) {
    // DEBUG_PRINTLN("Skipping Schedule: Waiting for Time Sync...");
    return; // EXIT IMMEDIATELY -> Frees up processor for OTA/MQTT
  }

  // 3. Now it is safe to use getLocalTime 
  struct tm timeinfo;
  if (!getLocalTime(&timeinfo)) return;

  // Convert everything to "Minutes from Midnight" for comparison
  int currentMins = (timeinfo.tm_hour * 60) + timeinfo.tm_min;
  int startMins   = (schedStartHour * 60) + schedStartMin;
  int endMins     = (schedEndHour * 60) + schedEndMin;

  // Handle overnight schedules (e.g. Start 23:00, End 05:00)
  bool inSchedule = false;
  if (startMins < endMins) {
    inSchedule = (currentMins >= startMins && currentMins < endMins);
  } else {
    inSchedule = (currentMins >= startMins || currentMins < endMins);
  }

  // ============================================================
  // THE NEW LOGIC: EDGE-TRIGGERED SCHEDULING
  // ============================================================
  // 'static' variables remember their value between function calls
  static bool wasInSchedule = false;
  static bool scheduleInitialized = false;

  // A. First run after boot & time sync
  if (!scheduleInitialized) {
    wasInSchedule = inSchedule;
    scheduleInitialized = true;
    
    // Safety: If the ESP32 reboots in the middle of the night (inside the window),
    // we want it to resume charging immediately.
    if (inSchedule && currentMode != 2) {
        DEBUG_PRINTLN("Boot: Woke up inside schedule window -> Forcing FAST");
        transitionToMode(2);
    }
    return; 
  }

  // B. Did we JUST ENTER the schedule window?
  if (inSchedule && !wasInSchedule) {
    DEBUG_PRINTLN("Schedule: Window STARTED -> Forcing FAST Mode");
    mqttLog("Schedule Action: Window STARTED -> Forcing FAST Mode");
    if (currentMode != 2) transitionToMode(2);
    wasInSchedule = true;
  } 
  
  // C. Did we JUST LEAVE the schedule window?
  else if (!inSchedule && wasInSchedule) {
    DEBUG_PRINTLN("Schedule: Window ENDED -> Forcing STOP");
    mqttLog("Schedule Action: Window ENDED -> Forcing STOP");
    // Only stop if we were actually Fast charging (so we don't kill a manual Eco session)
    if (currentMode == 2) transitionToMode(1);
    wasInSchedule = false;
  }
}

void loop() {
  ArduinoOTA.handle();
  esp_task_wdt_reset();

  // Checks WiFi signal every 30 seconds and reconnects if weak
  checkSignalHealth();
  
  // Print Memory Stats every 60 seconds
  if (millis() - lastHeapPrint > 60000) {
    lastHeapPrint = millis();
    DEBUG_PRINTF("Free Heap: %u bytes | Max Block: %u bytes\n", ESP.getFreeHeap(), ESP.getMaxAllocHeap());
  }

  checkSchedule(); // <--- Run the checkSchedule function
  checkFallbackTimeout();  
  publishSystemTime();
  vTaskDelay(pdMS_TO_TICKS(1));
}

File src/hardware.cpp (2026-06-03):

#include "hardware.h"
#include "globals.h"
#include "menu_system.h"
#include "web_server.h" 
#include "wifi_mqtt.h"

extern void mqttLog(const char* message);

// --- Task Handles ---
TaskHandle_t updateADC = NULL;
TaskHandle_t buttonReleaseTaskHandle = NULL;
TaskHandle_t returnHandlerTaskHandle = NULL;
TaskHandle_t rssiPublishTaskHandle = NULL;
TaskHandle_t counterNvsTaskHandle = NULL;

// --- Measurement Memory ---
// Prevents "flickering" 0 values if the loop is slightly out of sync with the 1kHz signal
float storedDuty = 0.0;
float storedAmps = 0.0;
unsigned long lastValidPulseTime = 0;


// ===============================
//  SETUP FUNCTION
// ===============================
void setupHardware() {
  pinMode(switchPin, OUTPUT);
  digitalWrite(switchPin, LOW); // Default OFF

  // Setup Buttons (Enter, Up, Down, Select)
  for (int i = 0; i < 4; i++) {
    pinMode(buttonPins[i], OUTPUT);
    digitalWrite(buttonPins[i], LOW);
    pinMode(returnButtonPins[i], INPUT_PULLUP);
  }

  // Attach Interrupts
  attachInterrupt(digitalPinToInterrupt(returnButtonPins[0]), handleReturn0, CHANGE);
  attachInterrupt(digitalPinToInterrupt(returnButtonPins[1]), handleReturn1, CHANGE);
  attachInterrupt(digitalPinToInterrupt(returnButtonPins[2]), handleReturn2, CHANGE);
  attachInterrupt(digitalPinToInterrupt(returnButtonPins[3]), handleReturn3, CHANGE);

  // ADC Setup
  pinMode(adcPin, INPUT);
  pinMode(adcInterruptPin, INPUT);
  
  // Measurement Interrupt
  attachInterrupt(digitalPinToInterrupt(adcInterruptPin), handleInterrupt, CHANGE);

  analogReadResolution(12);
  analogSetAttenuation(ADC_11db);

  DEBUG_PRINTLN("Hardware setup complete");
}

// ===============================
//  INTERRUPT SERVICE ROUTINES (ISRs)
// ===============================

// Generic handler for return buttons
void IRAM_ATTR handleReturnInterrupt(int index) {
    BaseType_t xHigherPriorityTaskWoken = pdFALSE;
    int state = digitalRead(returnButtonPins[index]);

    if (ignoreNextReturn[index]) {
        ignoreNextReturn[index] = false;
        return;
    }

    uint32_t ticks = (uint32_t)xTaskGetTickCountFromISR();
    if (ticks < maskUntil[index]) return;

    if (state == LOW) {
        portENTER_CRITICAL_ISR(&synch);
        returnTriggered[index] = true;
        returnTriggerTime[index] = ticks;
        portEXIT_CRITICAL_ISR(&synch);
    }
    maskUntil[index] = ticks + maskDurationTicks;
    portYIELD_FROM_ISR(xHigherPriorityTaskWoken);
}

// Wrappers
void IRAM_ATTR handleReturn0() { handleReturnInterrupt(0); }
void IRAM_ATTR handleReturn1() { handleReturnInterrupt(1); }
void IRAM_ATTR handleReturn2() { handleReturnInterrupt(2); }
void IRAM_ATTR handleReturn3() { handleReturnInterrupt(3); }

// ---------------------------------------------------------
//  RESTORED: Interrupt Handler
// ---------------------------------------------------------
void IRAM_ATTR handleInterrupt() {
  portENTER_CRITICAL_ISR(&synch); // LOCK
  
  if (digitalRead(adcInterruptPin) == HIGH) {
    pulseStart = micros();
  } else {
    pulseEnd = micros();
    pulseDetected = true;
  }
  
  portEXIT_CRITICAL_ISR(&synch); // UNLOCK
}

// ===============================
//  ADC & MEASUREMENT LOGIC
// ===============================
void measureDutyCycle() {
    // 1. Snapshot variables safely (CRITICAL SECTION)
    portENTER_CRITICAL(&synch);
    bool detected = pulseDetected;
    unsigned long localStart = pulseStart;
    unsigned long localEnd = pulseEnd;
    
    if(detected) pulseDetected = false; // Reset flag
    portEXIT_CRITICAL(&synch);

    // 2. Process New Pulse
    if (detected) {
        // J1772 Pulse logic: Width is the high time.
        // Basic check: End time must be after Start time
        if (localEnd > localStart) {
            long pulseWidth = localEnd - localStart;

            // Sanity Filter: J1772 is 1kHz (1000us period). 
            // Valid pulses are usually 100us (10%) to 960us (96%).
            // We ignore glitches > 1200us.
            if (pulseWidth < 1200 && pulseWidth > 80) { 
                
                // VALID PULSE: Update Memory
                // Calculation: (HighTime / 1000us) * 100%
                storedDuty = (static_cast<float>(pulseWidth) / 1000.0f) * 100.0f;

                // Clamp to legal range
                if (storedDuty > 99.9f) storedDuty = 100.0f;
                else if (storedDuty <= 5.0f) storedDuty = 0.0f; // J1772 usually min 6A (10%)

                storedAmps = storedDuty * 0.6f;
                lastValidPulseTime = millis(); // Refresh timestamp
            }
        }
    }
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

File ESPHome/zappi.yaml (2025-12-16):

esphome:
  name: zappi-controller
  platform: ESP32

  # Include our logic file
  includes:
    - zappi_logic.h

  # Initialize the Interrupt on Boot
  on_boot:
    priority: 600
    then:
      - lambda: |-
          setup_zappi(3); // Setup GPIO 3 for Interrupts

esp32:
  board: esp32-s3-devkitc-1
  framework:
    type: arduino

wifi:
  ssid: "YOUR_WIFI_SSID"
  password: "YOUR_WIFI_PASS"
  
  # Enable fallback hotspot in case wifi fails
  ap:
    ssid: "Zappi-Fallback"
    password: "password123"

# Enable Home Assistant API
api:

# Enable OTA updates
ota:
  - platform: esphome


captive_portal:
  
globals:
   - id: current_mode_index
     type: int
     restore_value: true # Remembers state after reboot
     initial_value: '0'  # 0 = Stopped    

# --- SENSORS (Using Template Platform) ---
sensor:
  # 1. THE DUTY CYCLE SENSOR (Uses C++ logic for interrupts)
  - platform: template
    name: "Zappi Duty Cycle"
    unit_of_measurement: "%"
    accuracy_decimals: 1
    update_interval: 1s
    lambda: |-
      return get_zappi_duty();

  - platform: template
    name: "Zappi Pilot Amps"
    unit_of_measurement: "A"
    accuracy_decimals: 1
    update_interval: 1s
    lambda: |-
      return get_zappi_duty() * 0.6;

  # 2. THE PEAK ADC SENSOR (Reads Voltage)
  - platform: template
    name: "Zappi Peak ADC"
    id: zappi_peak_adc
    update_interval: 1s
    accuracy_decimals: 0
    lambda: |-
      // Scan for 15ms to find the highest voltage peak
      int max_val = 0;
      unsigned long start = millis();
      while (millis() - start < 15) {
        int v = analogRead(8); 
        if (v > max_val) max_val = v;
      }
      return max_val;
    
    # 3. UPDATE STATUS TEXT BASED ON YOUR RANGES
    on_value:
      then:
        - lambda: |-
            int v = id(zappi_peak_adc).state;
            
            // Your Custom Ranges
            if (v >= 3600) {
              id(zappi_status).publish_state("Unplugged (A)");
            } 
            else if (v >= 3100) {
              id(zappi_status).publish_state("Connected (B)");
            } 
            else if (v >= 2500) {
              id(zappi_status).publish_state("Charging (C)");
            } 
            else if (v >= 1900) {
              id(zappi_status).publish_state("Ventilation (D)");
            } 
            else if (v >= 1500) {
              id(zappi_status).publish_state("No Power (E)");
            } 
            else {
              id(zappi_status).publish_state("Error (F)");
            }

# Translate Raw State Number to Text
text_sensor:
  - platform: template
    name: "Zappi Status"
    id: zappi_status
  - platform: template
    name: "Zappi Target Mode"
    id: zappi_target_mode
    update_interval: 0s # Updates only when triggered
    lambda: |-
      int i = id(current_mode_index);
      if (i == 0) return {"Stopped"};
      if (i == 1) return {"Fast"};
      if (i == 2) return {"Eco"};
      if (i == 3) return {"Eco++"};
      return {"Unknown"};    

# --- BUTTON CONTROLS & RELAY ---
switch:
  # 1. The Relay on GPIO 17
  - platform: gpio
    pin: 17
    id: zappi_relay
    name: "Zappi Relay"
    # Note: If your relay triggers when 'OFF' instead of 'ON', set inverted: true
    inverted: false 

  # 2. The Internal Buttons (Hidden triggers for the momentary buttons below)
  - platform: gpio
    pin: 
      number: 4
      inverted: true 
    id: btn_enter_relay
    internal: true 

  - platform: gpio
    pin: 5
    id: btn_up_relay
    internal: true

  - platform: gpio
    pin: 6
    id: btn_down_relay
    internal: true
    
  - platform: gpio
    pin: 7
    id: btn_select_relay
    internal: true

# Home Assistant Clickable Buttons
button:
  - platform: template
    name: "Zappi Enter"
    on_press:
      - switch.turn_on: btn_enter_relay
      - delay: 200ms
      - switch.turn_off: btn_enter_relay

  - platform: template
    name: "Zappi Up"
    on_press:
      # 1. Physically click the relay
      - switch.turn_on: btn_up_relay
      - delay: 200ms
      - switch.turn_off: btn_up_relay
      
      # 2. Cycle the State UP (0->1->2->3->0)
      - lambda: |-
          id(current_mode_index) += 1;
          if (id(current_mode_index) > 3) {
            id(current_mode_index) = 0;
          }
          id(zappi_target_mode).update();

  - platform: template
    name: "Zappi Down"
    on_press:
      # 1. Physically click the relay
      - switch.turn_on: btn_down_relay
      - delay: 200ms
      - switch.turn_off: btn_down_relay
      
      # 2. Cycle the State DOWN (0->3->2->1->0)
      - lambda: |-
          id(current_mode_index) -= 1;
          if (id(current_mode_index) < 0) {
            id(current_mode_index) = 3;
          }
          id(zappi_target_mode).update();

  - platform: template
    name: "Zappi Select"
    on_press:
      - switch.turn_on: btn_select_relay
      - delay: 200ms
      - switch.turn_off: btn_select_relay    

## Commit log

2025-12-16 Initial release
    [local-zappi-power-B_Cu.gbr, local-zappi-power-B_Mask.gbr, local-zappi-power-B_Silks.gbr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]
2025-12-23 Swap Switch for Buttons in MQTT
    [hardware.cpp]
2026-02-02 stop high current draws during AP scan
